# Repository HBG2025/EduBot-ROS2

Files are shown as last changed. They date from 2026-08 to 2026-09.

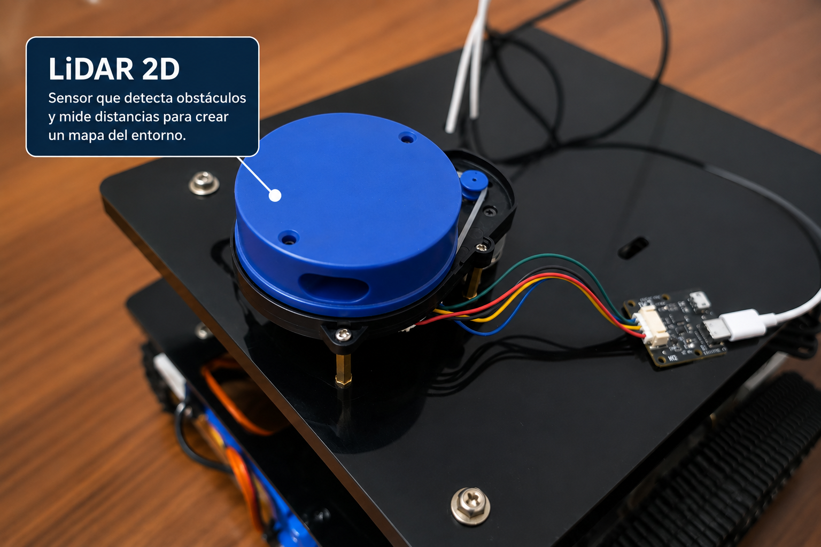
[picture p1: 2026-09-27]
IMG/file_000000006aa4820eb42d896be8eed414.png

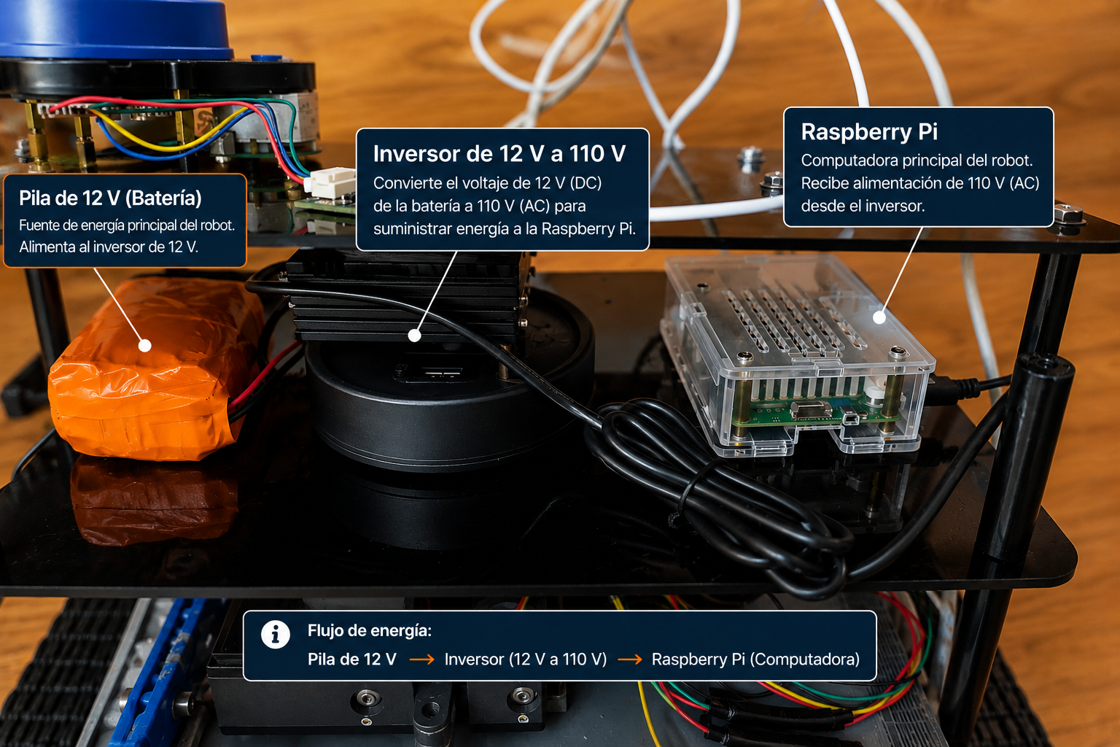
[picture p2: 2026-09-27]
IMG/file_00000000703c820e94ae82b6373de203.png

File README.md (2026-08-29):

<div align="center">

# 🤖 EduBot-ROS2

### Educational tracked robot with ROS 2, Raspberry Pi 5, ESP32, YDLIDAR X4 and BNO055







**Status:** hardware integration and first ROS 2 nodes have been experimentally tested.  
**Source-code upload:** pending; the project source files will be added progressively.

</div>

---

## 📌 Overview

**EduBot-ROS2** is an educational tracked mobile robot designed as a hands-on platform for learning:

- embedded programming with ESP32;
- ROS 2 node development;
- serial communication between ROS 2 and a microcontroller;
- 2D LiDAR acquisition;
- inertial sensing with a BNO055 IMU;
- encoder-based motion estimation;
- basic reactive obstacle avoidance;
- progressive integration of perception, decision-making and actuation.

The current platform uses a **Raspberry Pi 5 running Ubuntu 24.04 and ROS 2 Jazzy** for high-level tasks, while an **ESP32** handles the low-level motor interface, encoder acquisition and BNO055 reading.

The project is related to the architecture explored in the research article:

> H. B. Guerrero, D. C. Montenegro and A. L. Jutinico,  
> **“Reactive fuzzy control and field validation of a low-cost autonomous tracked robot for plantain crop row following,”**  
> *Engineering Research Express*, vol. 8, 045227, 2026.  
> DOI: https://doi.org/10.1088/2631-8695/ae458e

The educational platform intentionally starts from simpler ROS 2 interfaces and behaviors before moving toward the more complete perception-and-control architecture described in that work.

---

# 🧠 System architecture

```mermaid
flowchart TD

    X4["🟢 YDLIDAR X4"]
    LIDAR(["lidar_node"])
    OA(["obstacle_avoidance"])
    SB(["serial_bridge"])
    ESP["ESP32"]
    IMU["BNO055 IMU"]
    ENC["Wheel encoders"]
    DRV["Motor driver"]
    MOT["Tracked DC motors"]

    X4 -->|"USB serial / 128000 baud"| LIDAR

    LIDAR -->|"/lidar/distancia<br/>std_msgs/Float32"| OA

    OA -->|"/robot/comando<br/>std_msgs/String"| SB

    SB -->|"USB serial / 115200 baud"| ESP
    ESP -->|"status / IMU data / messages"| SB

    IMU -->|"I²C"| ESP
    ENC -->|"quadrature pulses"| ESP

    ESP -->|"direction + PWM"| DRV
    DRV --> MOT
```

The current ROS 2 implementation is deliberately modular:

| Component | Role |
|---|---|
| `serial_bridge` | Bidirectional communication between ROS 2 and the ESP32 |
| `lidar_node` | Reads the YDLIDAR X4 and publishes a processed distance |
| `obstacle_avoidance` | Makes a simple reactive decision based on LiDAR distance |
| ESP32 firmware | Motor actuation, encoder reading, BNO055 acquisition and local motion routines |

---

# ✅ Current verified functionality

The following functions have already been tested on the physical robot:

- [x] ESP32 firmware running with PlatformIO.
- [x] Both tracked motors operating in the correct direction.
- [x] Quadrature encoders connected and read by the ESP32.
- [x] BNO055 detected and read through I²C.
- [x] ROS 2 Jazzy running on Raspberry Pi 5.
- [x] ROS 2 ↔ ESP32 communication through `serial_bridge`.
- [x] High-level text commands sent from ROS 2 to the ESP32.
- [x] YDLIDAR X4 working through the YDLidar SDK.
- [x] LiDAR measurement from a ROS 2 node.
- [x] `/lidar/distancia` topic.
- [x] First reactive obstacle-avoidance node.
- [x] Obstacle threshold configured at **15 cm**.
- [x] Safety hysteresis configured at **20 cm**.
- [x] Corrective turn command of **45°**.

---

# 🔩 Hardware

## Main components

| Device | Function |
|---|---|
| Raspberry Pi 5 | ROS 2 high-level processing |
| ESP32 | Embedded motor/sensor controller |
| YDLIDAR X4 | 2D environment ranging |
| BNO055 | Yaw and angular-rate sensing |
| 2 × DC gear motors | Differential tracked locomotion |
| 2 × quadrature encoders | Wheel/motor motion feedback |
| Motor driver | Power stage for both motors |
| Tracked chassis | Mobile platform |

---

# 🔌 ESP32 pin assignment

The current tested pin assignment is:

| Function | ESP32 GPIO |
|---|---:|
| Motor A enable / PWM (`ENA`) | 25 |
| Motor A direction (`IN1`) | 27 |
| Motor A direction (`IN2`) | 26 |
| Motor B enable / PWM (`ENB`) | 14 |
| Motor B direction (`IN3`) | 13 |
| Motor B direction (`IN4`) | 18 |
| Left encoder A | 34 |
| Left encoder B | 35 |
| Right encoder A | 32 |
| Right encoder B | 33 |
| BNO055 SDA | 21 |
| BNO055 SCL | 22 |

> ⚠️ **Important:** GPIO12 was initially used for one motor-driver direction input.  
> This caused ESP32 boot problems (`invalid header: 0xffffffff`) because GPIO12 is a strapping-related pin on the ESP32.  
> The signal was moved to **GPIO18**.

The motor-direction definitions were also inverted in software so that the command `adelante` physically moves both tracks forward.

---

# 🖥️ Software environment

The current development environment is:

- Ubuntu 24.04
- ROS 2 Jazzy
- Python 3.12
- PlatformIO / Arduino framework for ESP32
- YDLidar SDK
- PySerial
- Git / GitHub CLI

---

# 📁 Planned repository structure

The source files will be uploaded progressively.

```text
EduBot-ROS2/
│
├── README.md
├── .gitignore
│
├── esp32/
│   └── firmware/
│
├── ros2_ws/
│   └── src/
│       ├── edubot_serial_bridge/
│       ├── edubot_lidar/
│       └── edubot_navigation/
│
├── docs/
│   ├── wiring/
│   ├── tests/
│   └── reports/
│
└── diagrams/
```

The ROS 2 generated directories should **not** be committed:

```text
build/
install/
log/
```

A suitable `.gitignore` is:

```gitignore
# ROS 2
build/
install/
log/

# Python
__pycache__/
*.pyc
*.pyo
*.pyd

# Editors
.vscode/
.idea/

# Temporary files
*.swp
*~
```

---

# 🛰️ USB devices on the Raspberry Pi

The ESP32 and the YDLIDAR interface may both appear as Silicon Labs CP2102 USB-to-UART devices.

Because both devices can expose very similar USB identification information, relying only on:

```bash
/dev/ttyUSB0
/dev/ttyUSB1
```

may be fragile.

For this robot, the devices were distinguished by their **physical USB path**:

```bash
ls -l /dev/serial/by-path/
```

> The exact `by-path` names depend on which physical Raspberry Pi USB connectors are used.  
> Keep each device connected to the same physical port when using fixed `by-path` configuration.

---

# 🧭 ROS 2 nodes

## 1. `serial_bridge`

### Purpose

`serial_bridge` provides communication between ROS 2 and the ESP32.

It subscribes to:

```text
/robot/comando
```

Message type:

```text
std_msgs/msg/String
```

Typical commands include:

```text
pose
bno_valores
adelante
parar
avanzar 20
girar 30
girar -30
```

### Data path

```mermaid
sequenceDiagram
    participant ROS as ROS 2 node
    participant SB as serial_bridge
    participant ESP as ESP32

    ROS->>SB: /robot/comando
    SB->>ESP: "avanzar 20\n"
    ESP->>ESP: execute local motion routine
    ESP-->>SB: status / sensor messages
```

### Run

```bash
source /opt/ros/jazzy/setup.bash
source ~/edubot_ws/install/setup.bash

ros2 run edubot_serial_bridge serial_bridge
```

### Basic test

From another terminal:

```bash
source /opt/ros/jazzy/setup.bash
source ~/edubot_ws/install/setup.bash

ros2 topic pub --once \
/robot/comando \
std_msgs/msg/String \
"{data: 'pose'}"
```

Test the IMU:

```bash
ros2 topic pub --once \
/robot/comando \
std_msgs/msg/String \
"{data: 'bno_valores'}"
```

Test a short movement:

```bash
ros2 topic pub --once \
/robot/comando \
std_msgs/msg/String \
"{data: 'avanzar 20'}"
```

Stop:

```bash
ros2 topic pub --once \
/robot/comando \
std_msgs/msg/String \
"{data: 'parar'}"
```

---

# 📡 YDLIDAR X4

The X4 was experimentally validated with the following SDK configuration:

```python
laser.setlidaropt(ydlidar.LidarPropSerialBaudrate, 128000)
laser.setlidaropt(ydlidar.LidarPropLidarType, ydlidar.TYPE_TRIANGLE)
laser.setlidaropt(ydlidar.LidarPropDeviceType, ydlidar.YDLIDAR_TYPE_SERIAL)
laser.setlidaropt(ydlidar.LidarPropScanFrequency, 10.0)
laser.setlidaropt(ydlidar.LidarPropSampleRate, 9)
laser.setlidaropt(ydlidar.LidarPropSingleChannel, True)
```

These values correspond to the configuration that worked on the physical sensor used in this project.

---

# 🛠️ YDLidar SDK installation

Install the required packages:

```bash
sudo apt update

sudo apt install -y \
git \
cmake \
pkg-config \
swig \
build-essential \
python3-dev \
python3-pip
```

Clone the SDK:

```bash
cd ~
git clone https://github.com/YDLIDAR/YDLidar-SDK.git
```

Build it:

```bash
cd ~/YDLidar-SDK
mkdir -p build
cd build
cmake ..
make -j4
sudo make install
```

On the tested Raspberry Pi, the wrapper was installed under:

```text
/usr/local/lib/python3/dist-packages/
```

If Python does not find it, add this to `~/.bashrc`:

```bash
export PYTHONPATH=/usr/local/lib/python3/dist-packages:$PYTHONPATH
```

Reload:

```bash
source ~/.bashrc
```

Test:

```bash
python3 -c "import ydlidar; print('YDLIDAR Python OK')"
```

Expected result:

```text
YDLIDAR Python OK
```

> Do not use `sudo python3` for normal LiDAR scripts unless it is absolutely necessary.  
> `sudo` may not preserve the user's `PYTHONPATH`.

---

# 📏 `lidar_node`

The first educational LiDAR node publishes a processed distance:

```text
/lidar/distancia
```

Message type:

```text
std_msgs/msg/Float32
```

The current implementation uses a small angular sector around approximately **90°** and computes an averaged projected distance from valid LiDAR points.

This node intentionally does **not** publish a complete `LaserScan` yet. That will be introduced in a later stage.

### Run

```bash
source /opt/ros/jazzy/setup.bash
source ~/edubot_ws/install/setup.bash
ros2 run edubot_lidar lidar_node
```

### Inspect the topic

```bash
ros2 topic echo /lidar/distancia
```

---

# 🚧 Reactive obstacle avoidance — Version 1

The first obstacle-avoidance experiment uses a simple ROS 2 state machine.

Current parameters:

```text
Obstacle threshold : 0.15 m
Free-path threshold: 0.20 m
Avoidance turn     : 45°
```

The difference between **15 cm** and **20 cm** creates hysteresis and prevents rapid switching between `adelante` and `parar` near a single threshold.

## Decision logic

```mermaid
flowchart TD

    A["Read /lidar/distancia"]
    B{"Distance ≤ 0.15 m?"}
    C["Continue forward"]
    D["Send: parar"]
    E["Send: girar 45"]
    F["Wait for turn"]
    G{"Distance ≥ 0.20 m?"}
    H["Send: adelante"]
    I["Repeat avoidance turn"]

    A --> B
    B -- No --> C
    C --> A
    B -- Yes --> D
    D --> E
    E --> F
    F --> G
    G -- Yes --> H
    H --> A
    G -- No --> I
    I --> E
```

---

# 🧩 `obstacle_avoidance`

The node:

- subscribes to `/lidar/distancia`;
- publishes commands on `/robot/comando`;
- stops the robot when the measured distance is 15 cm or less;
- requests a 45° turn;
- checks the LiDAR again;
- resumes forward motion when at least 20 cm is available.

### Run

```bash
source /opt/ros/jazzy/setup.bash
source ~/edubot_ws/install/setup.bash
ros2 run edubot_navigation obstacle_avoidance
```

---

# ▶️ Running the complete current system

Three terminals are currently used.

## Terminal 1 — ESP32 bridge

```bash
source /opt/ros/jazzy/setup.bash
source ~/edubot_ws/install/setup.bash
ros2 run edubot_serial_bridge serial_bridge
```

## Terminal 2 — LiDAR

```bash
source /opt/ros/jazzy/setup.bash
source ~/edubot_ws/install/setup.bash
ros2 run edubot_lidar lidar_node
```

## Terminal 3 — obstacle avoidance

```bash
source /opt/ros/jazzy/setup.bash
source ~/edubot_ws/install/setup.bash
ros2 run edubot_navigation obstacle_avoidance
```

---

# 🧪 Recommended test procedure

## 1. ESP32-only test

Before starting ROS 2, the ESP32 can be tested directly:

```bash
python3 -m serial.tools.miniterm /dev/ttyUSB0 115200
```

Useful commands:

```text
help
pose
bno_valores
avanzar 20
girar 30
parar
```

Exit `miniterm` using:

```text
Ctrl+T
Q
```

The serial port must be free before starting `serial_bridge`.

## 2. ROS 2 communication test

Start `serial_bridge`, then publish:

```bash
ros2 topic pub --once \
/robot/comando \
std_msgs/msg/String \
"{data: 'pose'}"
```

The bridge should display:

```text
ROS2 -> ESP32: pose
ESP32 -> ...
```

## 3. ROS 2 LiDAR test

Run:

```bash
ros2 run edubot_lidar lidar_node
```

Then:

```bash
ros2 topic echo /lidar/distancia
```

Move an object in the measured sector and verify that the distance changes.

## 4. Obstacle-avoidance test

> ⚠️ **First test with the tracks lifted from the ground.**

Expected behavior:

```text
distance > 0.20 m
        ↓
     adelante

distance ≤ 0.15 m
        ↓
      parar
        ↓
    girar 45
        ↓
  measure again
```

Only after verifying the complete command chain should the robot be tested on the floor.

---

# 🛑 Emergency stop

Manual ROS 2 stop command:

```bash
ros2 topic pub --once \
/robot/comando \
std_msgs/msg/String \
"{data: 'parar'}"
```

> ⚠️ **Hardware safety remains mandatory.**  
> The present ESP32 firmware still contains blocking movement routines. During some maneuvers a new serial command may not be processed immediately. For early experiments, keep physical access to the motor-power switch or power supply.

---

# ⚠️ Known limitations

This repository currently represents an **educational first stage**, not a complete autonomous navigation stack.

Current limitations include:

1. The LiDAR ROS 2 node publishes one processed distance rather than a full 360° `sensor_msgs/LaserScan`.
2. Obstacle avoidance currently reacts to one measured sector.
3. The avoidance turn is fixed at 45°.
4. The current behavior does not yet compare free space on the left and right.
5. Some ESP32 motion functions are blocking.
6. ROS 2 commands are currently text strings.
7. The IMU is read by the ESP32 rather than exposed as a dedicated ROS 2 IMU topic.
8. No SLAM or global planner is used.
9. RViz integration is intentionally postponed.
10. Source files are still being organized for upload to this repository.

---

# 🗺️ Roadmap

```mermaid
flowchart LR

    A["✅ ROS 2 ↔ ESP32"]
    B["✅ BNO055"]
    C["✅ YDLIDAR X4"]
    D["✅ Basic obstacle avoidance"]
    E["⬜ Full 360° sectors"]
    F["⬜ Left/right free-space decision"]
    G["⬜ LaserScan topic"]
    H["⬜ Non-blocking ESP32 firmware"]
    I["⬜ Dedicated IMU topic"]
    J["⬜ ROS 2 launch files"]
    K["⬜ RViz"]
    L["⬜ Autonomous navigation"]

    A --> B --> C --> D --> E --> F --> G --> H --> I --> J --> K --> L
```

---

# 🧯 Troubleshooting notes

## ESP32 shows `invalid header: 0xffffffff`

Check whether GPIO12 is connected to an external circuit.

In this project, moving the motor-driver signal from GPIO12 to GPIO18 solved the boot problem.

## Motors rotate backwards

Current tested mapping:

```text
Motor A: IN1=27, IN2=26
Motor B: IN3=13, IN4=18
```

## `ModuleNotFoundError: No module named 'ydlidar'`

Check:

```bash
echo $PYTHONPATH
```

It should include:

```text
/usr/local/lib/python3/dist-packages
```

## Serial port is busy

Before starting `serial_bridge`, close:

- PlatformIO Serial Monitor;
- `miniterm`;
- other serial tools.

## ESP32 and LiDAR appear with confusing `ttyUSB` numbers

Check:

```bash
ls -l /dev/serial/by-path/
```

Use the physical USB path when stable device assignment is required.

---

# 📚 Related research

**Henry B. Guerrero, Danna C. Montenegro and Andrés L. Jutinico**  
*Reactive fuzzy control and field validation of a low-cost autonomous tracked robot for plantain crop row following*  
**Engineering Research Express**, 8, 045227, 2026.  
DOI: https://doi.org/10.1088/2631-8695/ae458e

That work used a Raspberry Pi 5, ESP32, 2D LiDAR, BNO055 IMU and ROS 2 for reactive under-canopy navigation. EduBot-ROS2 reuses the general hardware/software philosophy while simplifying the interfaces for educational development.

---

# 👥 Educational use

This repository is intended to support progressive laboratory activities in:

- embedded systems;
- mobile robotics;
- sensors and instrumentation;
- Python programming;
- ROS 2 publishers and subscribers;
- serial communication;
- feedback control;
- reactive robotics;
- autonomous navigation.

The goal is to make each software layer observable and modifiable before increasing the system complexity.

---

# 📄 License

A repository license has not yet been selected.

---

<div align="center">

### 🚜 From embedded control to autonomous robotics, one ROS 2 node at a time.

</div>

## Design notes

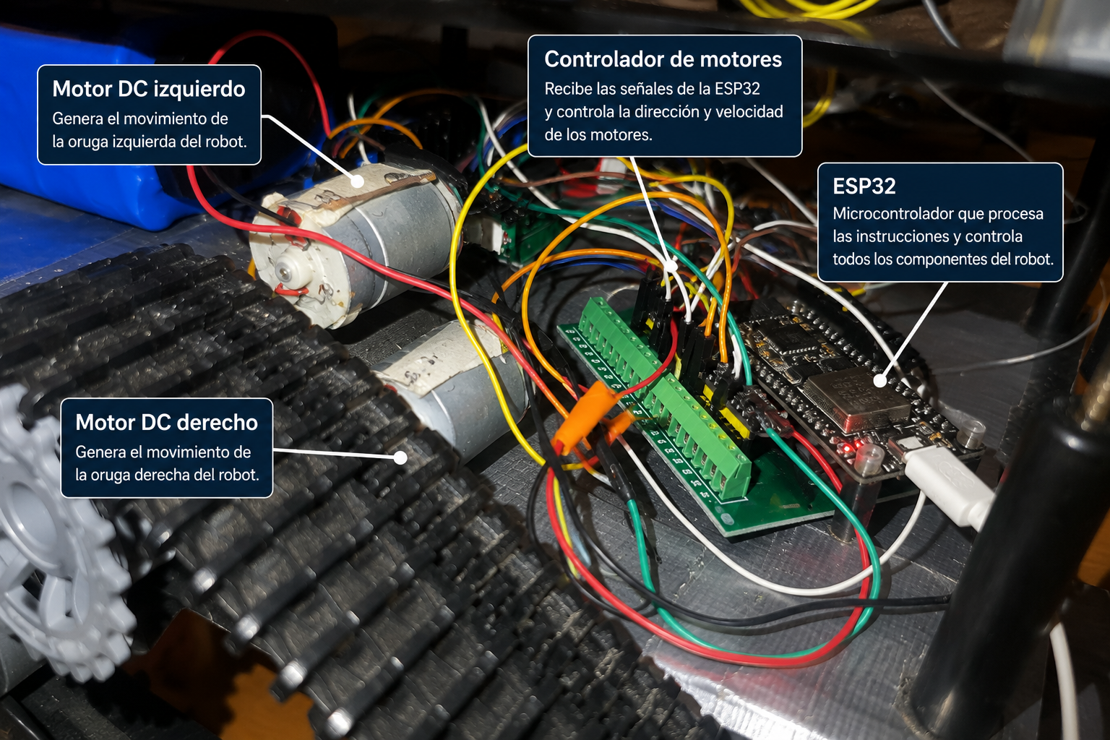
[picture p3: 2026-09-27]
IMG/file_000000007394820e8d9fce0545a17f0b.png

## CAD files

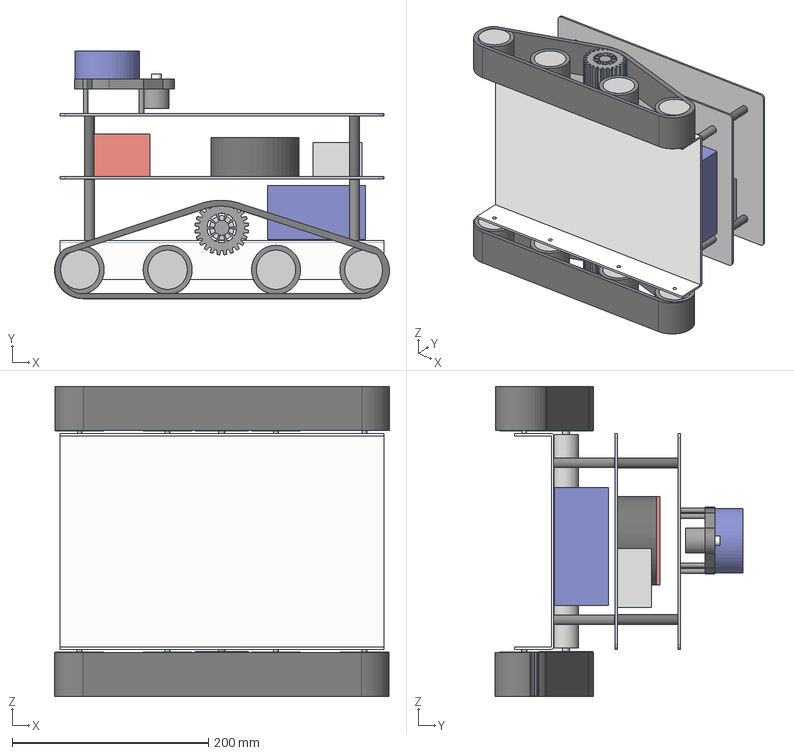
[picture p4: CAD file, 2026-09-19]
IMG/EduBot_Ensamble.step
341.3 x 252.2 x 315.9 mm

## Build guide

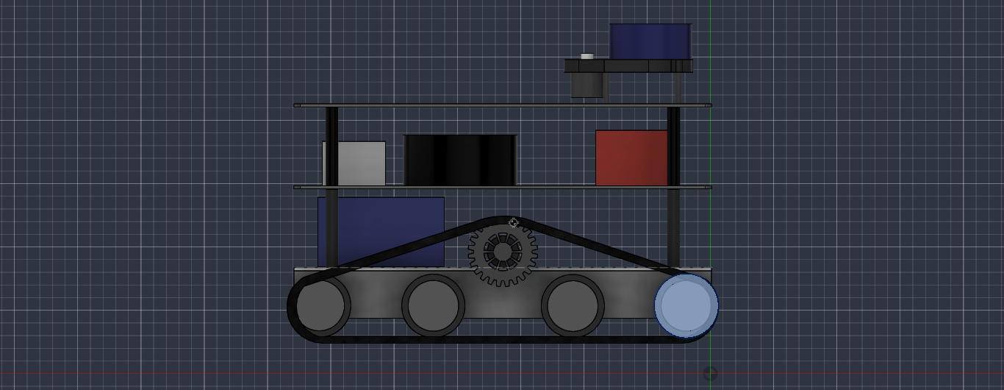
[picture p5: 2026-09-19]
IMG/EduBot_EnsambleVL1.png

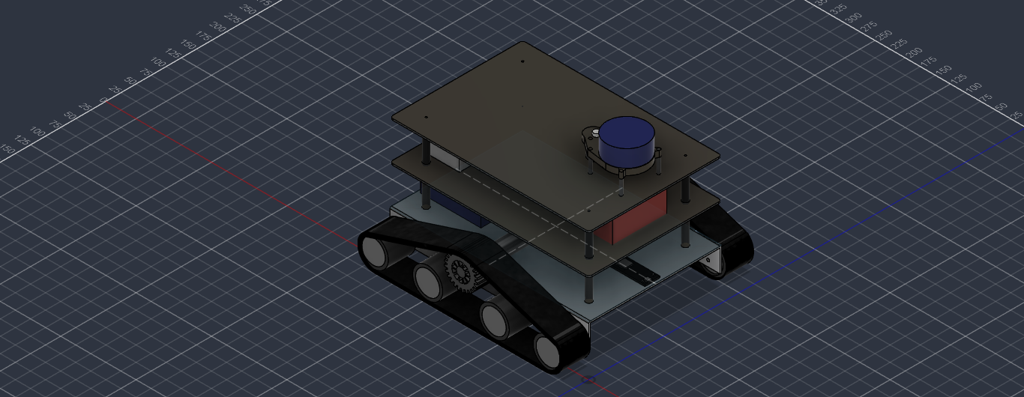
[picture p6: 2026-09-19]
IMG/EduBot_EnsambleNL.png

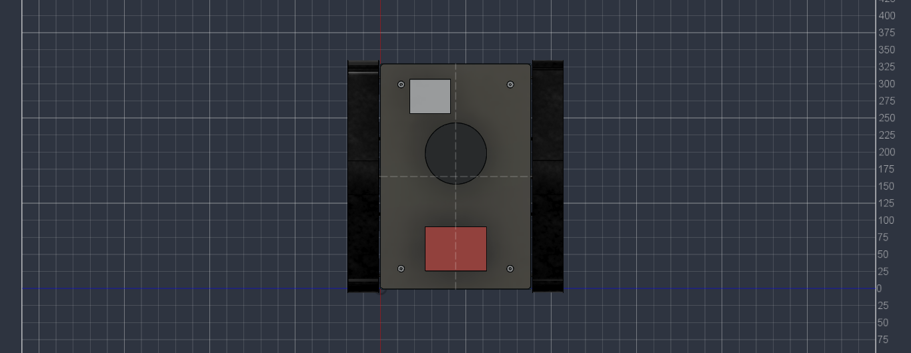
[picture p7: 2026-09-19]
IMG/EduBot_EnsambleLv2.png

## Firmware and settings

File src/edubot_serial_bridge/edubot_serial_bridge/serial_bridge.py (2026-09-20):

import rclpy
from rclpy.node import Node
from std_msgs.msg import String

import serial
import time

class SerialBridge(Node):

    def __init__(self):
        super().__init__('serial_bridge')

        # ==========================
        # PARÁMETROS SERIAL
        # ==========================
        self.declare_parameter('port', '/dev/serial/by-path/platform-xhci-hcd.1-usb-0:1:1.0-port0')
        self.declare_parameter('baud', 115200)

        puerto = self.get_parameter('port').value
        baud = self.get_parameter('baud').value

        # ==========================
        # ABRIR PUERTO SERIAL
        # ==========================
        try:
            self.serial_port = serial.Serial(
                port=puerto,
                baudrate=baud,
                timeout=0.05,
                dsrdtr=False,
                rtscts=False
            )

            self.serial_port.dtr = False
            self.serial_port.rts = False
            
            time.sleep(2.0)

            self.serial_port.reset_input_buffer()
            self.serial_port.reset_output_buffer()

            self.get_logger().info(
                f'Conectado al ESP32 en {puerto} a {baud} baudios'
            )

        except serial.SerialException as e:

            self.get_logger().error(
                f'No se pudo abrir el puerto serial: {e}'
            )

            self.serial_port = None

        # ==========================
        # SUSCRIPTOR ROS 2
        # ==========================
        self.suscriptor_comando = self.create_subscription(
            String,
            '/robot/comando',
            self.recibir_comando,
            10
        )

        # ==========================
        # TIMER PARA LEER ESP32
        # ==========================
        self.timer = self.create_timer(
            0.05,
            self.leer_serial
        )

        self.get_logger().info(
            'Esperando comandos en /robot/comando'
        )

    # ==========================
    # ROS 2 -> ESP32
    # ==========================
    def recibir_comando(self, msg):

        if self.serial_port is None:
            self.get_logger().error(
                'Puerto serial no disponible'
            )
            return

        comando = msg.data.strip()

        if not comando:
            return

        try:

            mensaje = comando + '\n'

            self.serial_port.write(
                mensaje.encode('utf-8')
            )

            self.get_logger().info(
                f'ROS2 -> ESP32: {comando}'
            )

        except serial.SerialException as e:

            self.get_logger().error(
                f'Error enviando comando: {e}'
            )

    # ==========================
    # ESP32 -> ROS 2
    # ==========================
    def leer_serial(self):

        if self.serial_port is None:
            return

        try:

            while self.serial_port.in_waiting > 0:

                linea = self.serial_port.readline()

                try:
                    texto = linea.decode('utf-8').strip()

                except UnicodeDecodeError:
                    self.get_logger().warning(
                    'Trama serial corrupta descartada'
                    )
                    return
                
                if texto:

                    self.get_logger().info(
                        f'ESP32 -> {texto}'
                    )

        except serial.SerialException as e:

            self.get_logger().error(
                f'Error leyendo puerto serial: {e}'
            )

    # ==========================
    # CIERRE
    # ==========================
    def destroy_node(self):

        if self.serial_port is not None:
            self.serial_port.close()

        super().destroy_node()


def main(args=None):

    rclpy.init(args=args)

    nodo = SerialBridge()

    try:

        rclpy.spin(nodo)

    except KeyboardInterrupt:

        pass

    nodo.destroy_node()

    rclpy.shutdown()


if __name__ == '__main__':
    main()

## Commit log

2026-09-19 Imágenes diseño 3D EduBot
    [EduBot_Ensamble.step]
2026-09-20 Actualizar LiDAR por sectores y control de evasión
